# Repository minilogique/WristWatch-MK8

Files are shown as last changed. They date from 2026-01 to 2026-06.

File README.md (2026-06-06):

# WristWatch Extruder with MK8 Filament Gear

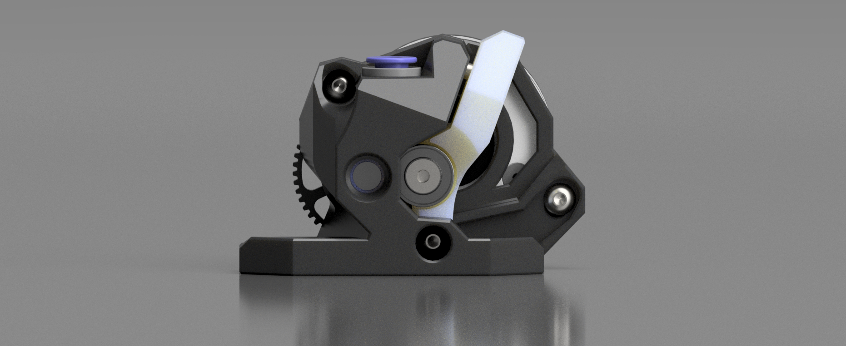
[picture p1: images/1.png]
Extruder Image 1

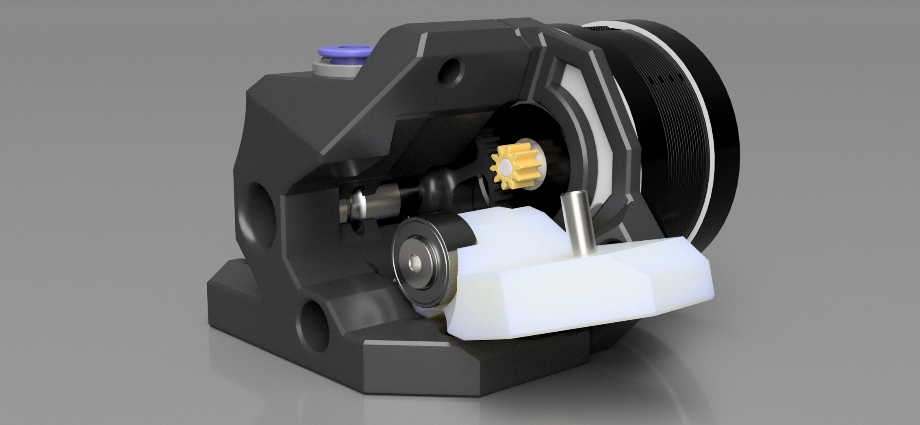
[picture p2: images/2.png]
Extruder Image 2


Comparison between BMG teeth and MK8 teeth that grip the filament.  
MK8 has a **0.5 mm smaller effective diameter** at the filament path (measured from tooth tips).

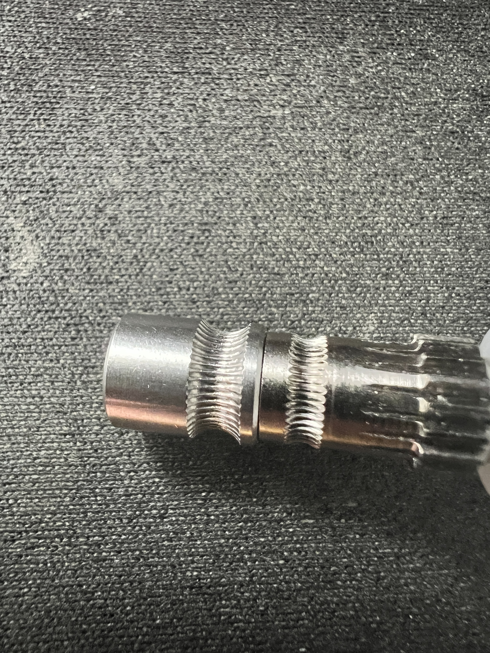
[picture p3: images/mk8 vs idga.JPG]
Teeth Comparison


Demonstration of pushing **95A TPU at 250 °C at 41 mm³/s**:  
https://www.youtube.com/shorts/knSDY8lV37g

So far after few hundred hours it has proven to be reliable and strong extruder for following materials: PETG, PLA, PPA-CF, ASA-GF, ABS+, TPU 95A, TPU 90A, PA6-GF25, PETG-CF, PLA woodfill, ASA-CF, PLA luminescent, PC-ABS, PC-PBT-GF20. 

---

## Assembly Notes

Assembly is identical to any **BMG gearset** or **WristWatch extruder**.  
Only the **main body** differs from the IDGA/RIDGA version.  
The **IDGA smooth bearing idler** can be reused as-is.

**Drive gear installation:**

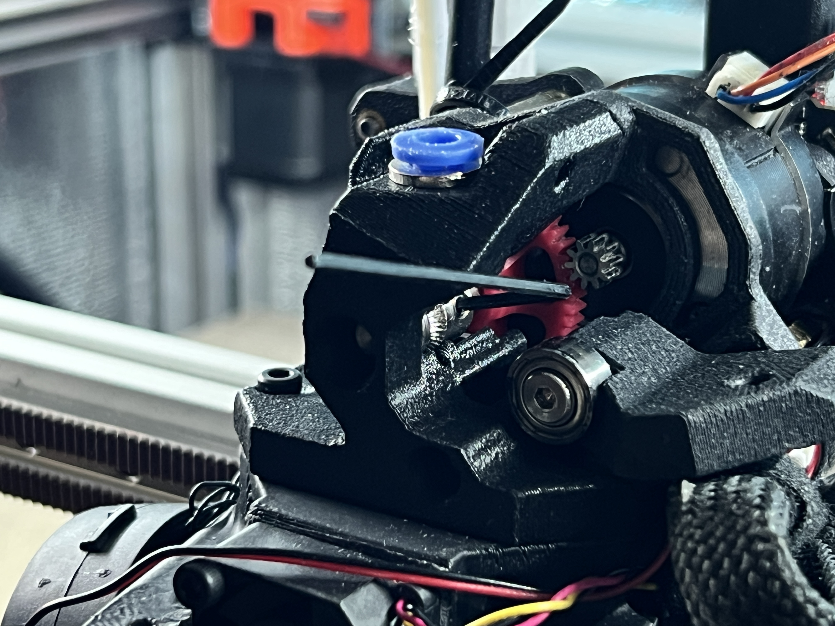
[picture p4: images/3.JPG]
Extruder Image 3

1. Leave the drive gear loose on the shaft.  
2. Push filament through the extruder.  
3. Wiggle the gear into correct alignment.  
4. Tighten the set screw only after alignment is perfect.

Use threadlocker where needed.  
MK8 gears are not perfectly centered like Bondtech/FYSETC billet gears, but they are dramatically cheaper.

ATTENTION - IF THE BEARING FOR THE SHAFT GETS MISALIGNED/SHIFTED AWAY FROM THE FILAMENT PATH, IT WILL CAUSE EXTRUSION ISSUES. MAKE SURE THE BEARING IS CENTERED WHEN INSTALLING AND CHECK IT WHEN DOING MAINTENANCE TO THE PRINTER!
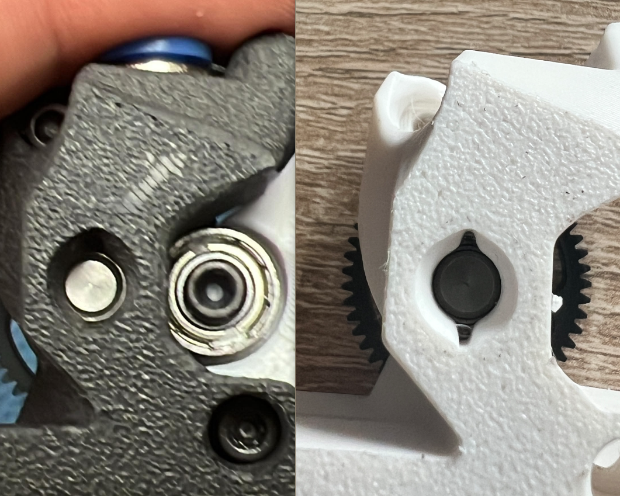
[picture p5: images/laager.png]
Extruder Image 3

---

# Bill of Materials (BOM)

## Main Drive Gear Components

| Item | Notes | Approx. Price |
|---|---|---|
| 50T reduction gear (Sherpa/WW/CW/Hex) | 5×28 mm shaft | ~5.5 € |
| MK8 drive gear (1.75 mm) | plastic hollowed gears are perfectly fine | 2.7 € single, or ~3 €/5 pcs (~0.60 €/pc)
| 2× MR85 smooth bearings | smooth type, no edges | ~4.7 €/10 pcs (~0.50 €/pc)
| 1× M3×16 flathead bolt | flathead is low profile and fits better | cents |
| 1× small-radius M3 washer | — | cents |

**Total cost with shipping: ~7 €**

---

## Main Hardware  
*(Same as A4T WW BMG / RIDGA / IDGA)*

- 2 × M3 thin square nuts  
- 2 × M3×20  
- 1 × M3×12  
- 1 × M3×16  
- 1 × M3×25  
- 1 × M3 thin washer  
- 1 × extruder spring  

---

## Smooth Idler Hardware

- 1 × 685‑2RS bearing  
- 1 × M3×16 flathead bolt  
- 1 × M3 thin washer  

---

# Performance Notes

- BMG clones have a **larger filament drive radius** and are often **more eccentric**, causing inconsistent extrusion.  
- MK8 diameter at tooth tips: **7.0 mm**  
- OEM Bondtech RIDGA: **7.5 mm**  
- MK8 teeth are **deeper**, improving grip.

### Rotation Distance

- Original RIDGA: `rotation_distance: 4.45`  
- MK8 setup: `rotation_distance: 4.0`  

This ~10% reduction increases torque by roughly the same amount.

### Real‑World Torque Evidence

Using ASA at **290 °C** through a **Goliath hotend** with a **0.5 mm non‑CHT nozzle**, the extruder pushed filament so hard that:

- 1.75 mm filament entered  
- 1.6 mm filament exited (melt zone saturated)  
- Filament remained in glass transition and “rebuilt” itself after extrusion

Idler tension should be higher — **let the teeth bite in** so without filament the idler rides the driven filament gear.

---

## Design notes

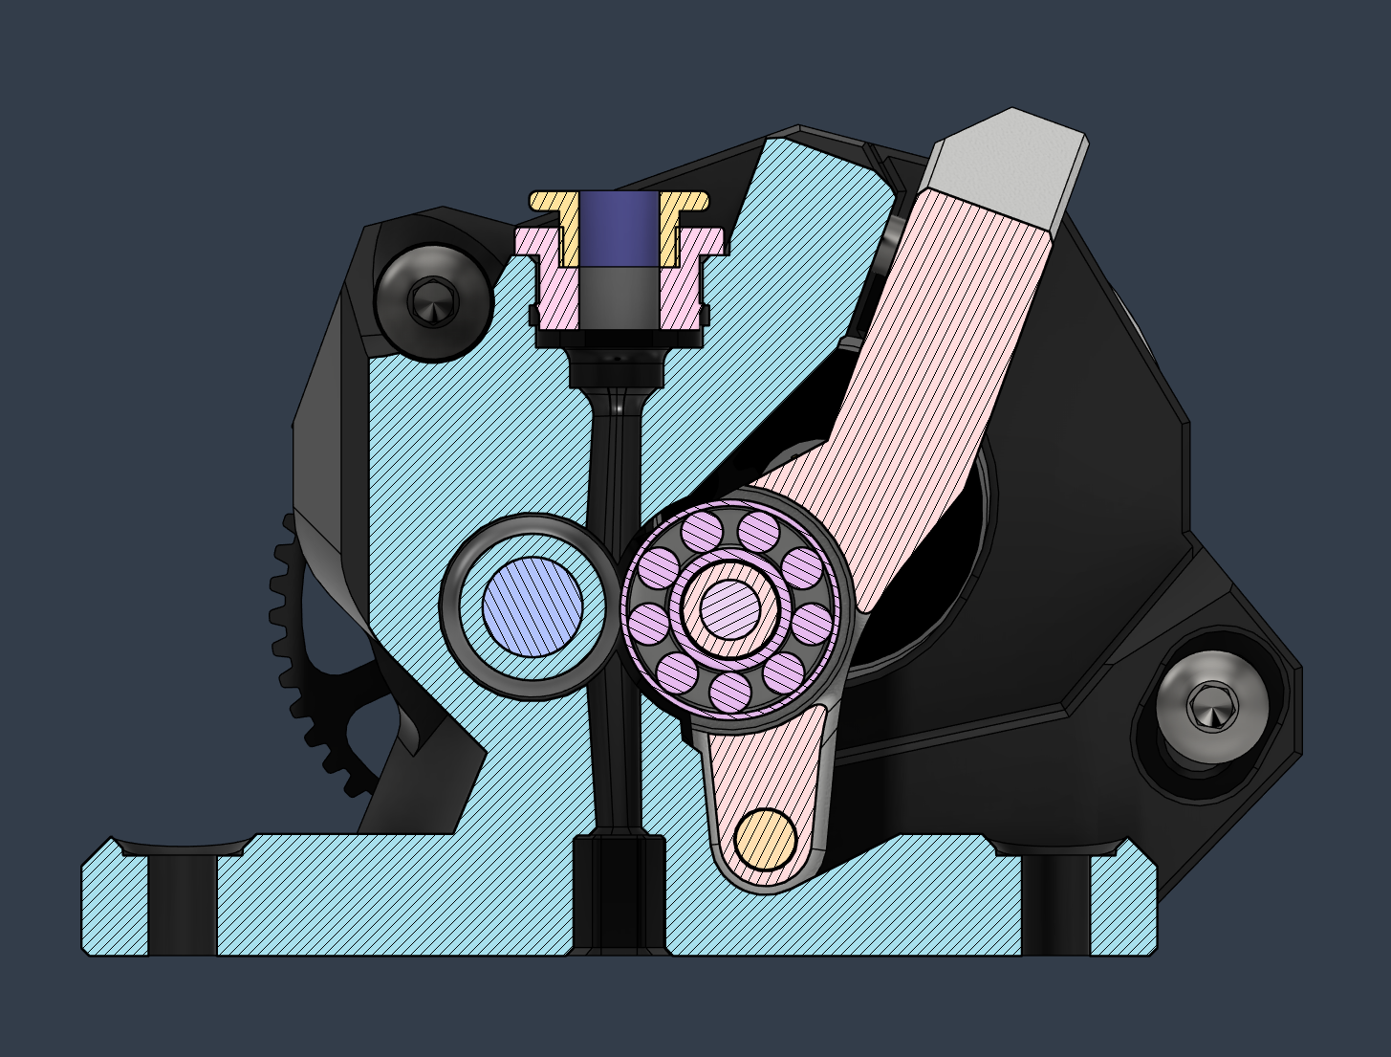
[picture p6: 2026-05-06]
images/internal.png

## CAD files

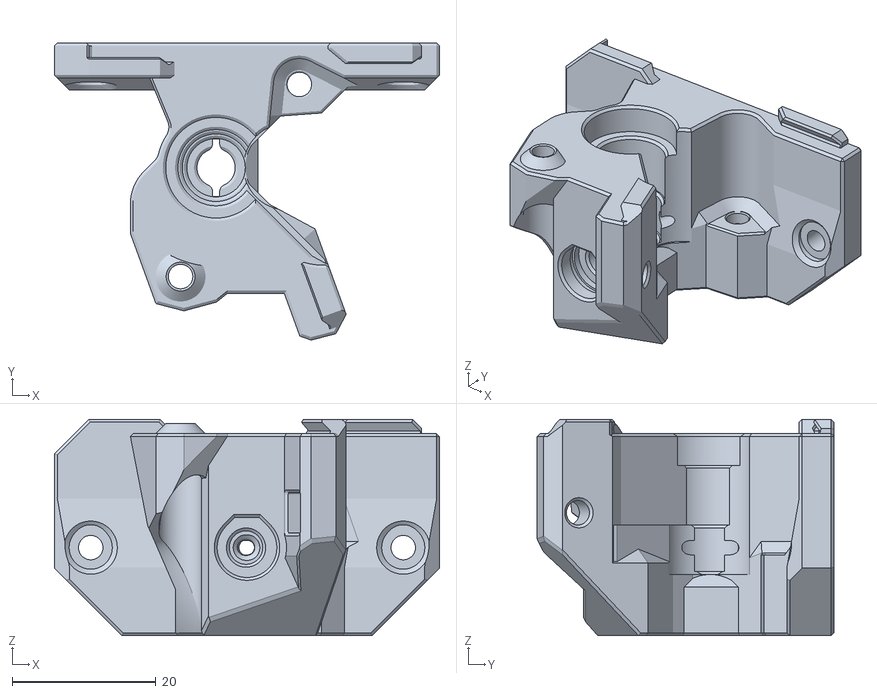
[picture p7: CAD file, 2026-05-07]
STLs/WW MK8 MAIN BODY.stl
53.6 x 41.4 x 30.1

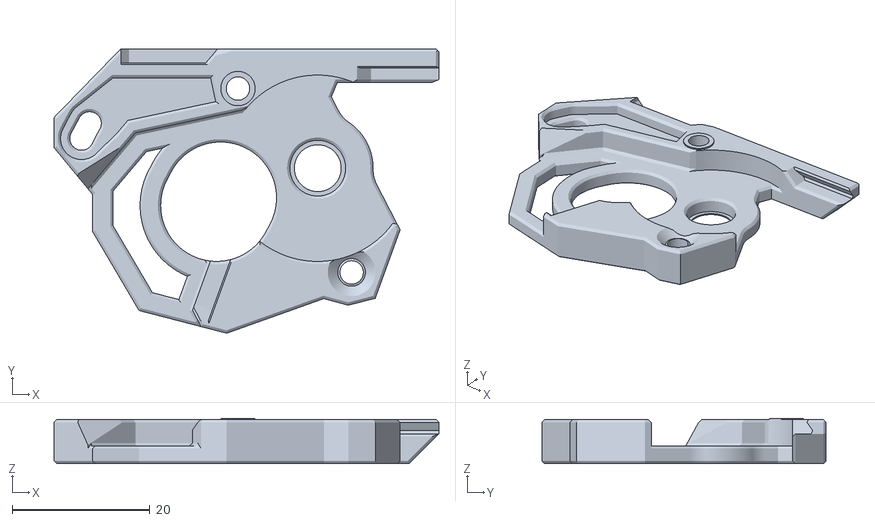
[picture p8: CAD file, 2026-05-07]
STLs/WWBMG MOTOR PLATE.stl
56.0 x 41.4 x 6.60

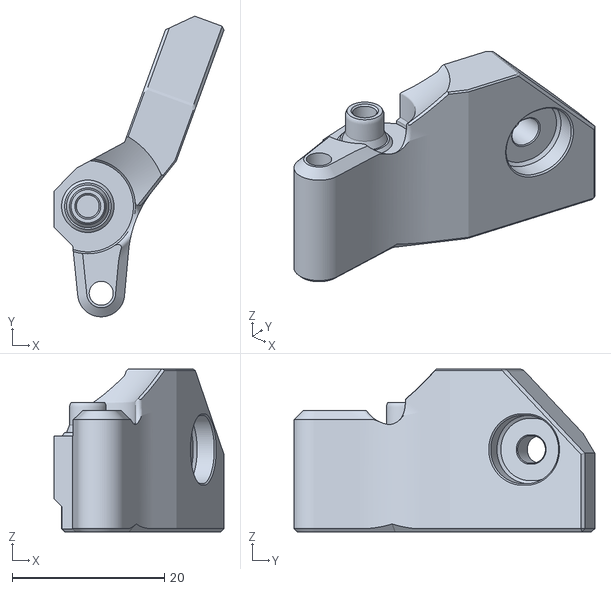
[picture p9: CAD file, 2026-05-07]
STLs/WWBMG SMOOTH IDLER TENSION ARM.stl
22.4 x 39.6 x 21.4

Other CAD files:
STLs/WWBMG BEEFIER MOTOR PLATE.stl

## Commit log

2026-01-28 first upload
    [WW MK8 MAIN BODY.3mf, WWBMG MOTOR PLATE.3mf, WWBMG SMOOTH IDLER TENSION ARM.3mf]
2026-02-27 updated clearances for printing softer TPUs for better pressure from idler before colliding with the main body; tweaked clearances of the idler tension arm
    [WW MK8 MAIN BODY.3mf, WWBMG SMOOTH IDLER TENSION ARM.3mf]
2026-02-27 Update WW MK8 MAIN BODY.3mf
    [WW MK8 MAIN BODY.3mf]
2026-03-02 Update WW MK8 MAIN BODY.3mf
    adjusted the shaft tunnel clearances;
    extended the internal bearing bore 0.4mm;
    [WW MK8 MAIN BODY.3mf]
2026-03-11 added photo and updated readme about adjusting the driven gear
2026-04-05 fixed clearances
    [WW MK8 MAIN BODY.3mf, WWBMG BEEFIER MOTOR PLATE.3mf, WWBMG SMOOTH IDLER TENSION ARM.3mf]
2026-04-09 updated extrusion rotation_distance to be more inline with other extruders
    getting access to more printers with my material profiles it turned out that 4.05 still slightly under-extruder at same material flowrate. 4.0 instead of 4.05 fixes that.
2026-04-11 filament path chamfer fix
    [WW MK8 MAIN BODY.3mf]
2026-04-11 Update WW MK8 MAIN BODY.3mf
    adjusted shaft bearing distances
    [WW MK8 MAIN BODY.3mf]
2026-05-06 minor tweaks to main body;
    [WW MK8 MAIN BODY.3mf]
2026-05-07 replaced 3MFs with STLs
    [WW MK8 MAIN BODY.3mf, WW MK8 MAIN BODY.stl, WWBMG BEEFIER MOTOR PLATE.3mf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]
